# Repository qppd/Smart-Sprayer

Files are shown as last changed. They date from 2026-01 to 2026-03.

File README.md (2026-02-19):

# Smart-Sprayer

## Overview

The Smart-Sprayer is an advanced IoT-enabled agricultural device built on the ESP32 microcontroller platform. It provides intelligent, automated pesticide spraying with weather-aware operation and user-friendly button-based scheduling. The system features ultrasonic level monitoring, GSM SMS notifications, LCD status display, and comprehensive feedback systems for professional agricultural applications.

### Key Operational Flow
1. **System Startup**: ESP32 initializes all hardware components
2. **Button Scheduling**: User sets spray time using ESP32 buttons
3. **Automated Monitoring**: System continuously checks time and weather
4. **Weather Validation**: Prevents spraying during rain conditions
5. **Smart Activation**: Activates pumps when conditions are optimal
6. **Level Monitoring**: Real-time container level checking during operation
7. **Feedback System**: Professional audio-visual status indicators

## Features

### Core Functionality
- **Button-Based Scheduling**: Intuitive time setting using ESP32 buttons with LCD menu navigation
- **Weather-Aware Operation**: Automatic rain detection prevents unnecessary spraying
- **Container Level Monitoring**: Real-time ultrasonic measurement with low-level warnings
- **Automated Spraying**: Scheduled activation with intelligent condition checking
- **Professional Feedback**: Commercial-grade LED patterns and industrial buzzer tones
- **GSM Notifications**: SMS alerts for completion, postponement, and system events
- **Network Resilience**: Automatic reconnection with SMS retry mechanisms

### Advanced Features
- **Dual Relay Control**: Independent pump/valve operation for precision spraying
- **RTC Timekeeping**: Accurate scheduling with NTP synchronization and battery backup
- **Firebase Integration**: Cloud data logging and remote monitoring capabilities
- **WiFi Management**: Automatic configuration with captive portal fallback
- **Serial Diagnostics**: Comprehensive command interface for testing and configuration
- **Modular Architecture**: Clean separation of concerns with dedicated config headers

### System Architecture
- **ESP32 Microcontroller**: Dual-core processing with WiFi/Bluetooth
- **Ultrasonic Sensors**: HC-SR04 for precise container level measurement
- **GSM Module**: SIM800L for SMS communication and network monitoring
- **LCD Display**: 20x4 I2C interface for status and menu navigation
- **Relay System**: Dual-channel control for spray actuators
- **Button Interface**: 4-button navigation (WiFi reset + 3 menu controls)
- **RTC Module**: DS1302 for reliable timekeeping
- **Audio/Visual**: Buzzer and dual LED status indicators

### Notification System
The Smart-Sprayer includes a comprehensive notification system for operational awareness:

- **SMS Alerts**: Automatic notifications for spraying events (completion, postponement, errors)
- **Retry Logic**: Failed SMS messages are automatically retried up to 3 times
- **Network Monitoring**: GSM network disconnection triggers automatic reconnection attempts
- **Commercial Feedback**: Professional LED blinking patterns and industrial buzzer tones
- **Status Indicators**: Visual and audible feedback for all system operations

## System Flowchart

The project includes a detailed flowchart diagram showing the complete operational process:

```
diagram/SmartSprayer_Flowchart.md
```

This flowchart illustrates the step-by-step process from ESP32 button scheduling through automated spraying cycles, including decision points for weather checking, time validation, and level monitoring.

### Container Level Calculation
The ultrasonic sensor measures the distance from the sensor to the surface of the pesticide in the container. To calculate the fill percentage:

1. Define a variable for the total height of the container (e.g., `CONTAINER_HEIGHT` in cm)
2. Measure the distance from the sensor to the liquid surface using the SR04 sensor
3. Calculate the filled height: `filledHeight = CONTAINER_HEIGHT - measuredDistance`
4. Calculate the percentage: `percentage = (filledHeight / CONTAINER_HEIGHT) * 100`

This allows precise monitoring of pesticide levels to prevent running out during spraying operations.

## Hardware Requirements

### Microcontroller
- ESP32 development board (ESP32-WROOM-32 recommended) with built-in WiFi and Bluetooth

### Sensors and Modules
- HC-SR04 ultrasonic distance sensor (2 units)
- 20x4 I2C LCD display module
- GSM module (SIM800L or compatible)
- 2-channel relay module (5V or 12V based on application)
- Buzzer module (active/passive buzzer)
- LED indicators (2 units: OK and Error status)
- DS1302 RTC module (for accurate timekeeping)
- Push buttons (4 units: WiFi reset + 3 for menu navigation)

### Additional Components
- SIM card for GSM module
- Power supply (5V for ESP32, appropriate voltage for relays)
- Jumper wires and breadboard for prototyping
- Antenna for GSM module
- Internet connection for WiFi and Firebase functionality

### Pin Configuration
The system uses centralized pin definitions in `PINS_CONFIG.h` for easy modification:

| Component | Pin | Function | Notes |
|---|-----|---|---|
| Ultrasonic Sensor 1 | GPIO 12 | Trig | Trigger pin for ultrasonic pulses |
| Ultrasonic Sensor 1 | GPIO 13 | Echo | Echo pin for distance measurement |
| Ultrasonic Sensor 2 | GPIO 14 | Trig | Trigger pin for second sensor |
| Ultrasonic Sensor 2 | GPIO 16 | Echo | Echo pin for second sensor |
| Relay Module | GPIO 4 | Relay 1 Control | Controls first spray actuator |
| Relay Module | GPIO 5 | Relay 2 Control | Controls second spray actuator |
| GSM Module | GPIO 10 | RX | Receive data from GSM module |
| GSM Module | GPIO 11 | TX | Transmit data to GSM module |
| LCD Display | GPIO 21 | SDA | I2C data line (default ESP32 I2C) |
| LCD Display | GPIO 22 | SCL | I2C clock line (default ESP32 I2C) |
| Buzzer | GPIO 17 | Control | Audio alert output |
| System OK LED | GPIO 18 | Status | Indicates system OK state |
| System Error LED | GPIO 19 | Status | Indicates system error state |
| WiFi Reset Button | GPIO 23 | Input | Triggers WiFi manager reset (hold 3s) |
| Menu Up Button | GPIO 25 | Input | Menu navigation up |
| Menu Down Button | GPIO 26 | Input | Menu navigation down |
| Menu Select Button | GPIO 27 | Input | Menu select/save |
| DS1302 CE | GPIO 32 | Output | RTC chip enable |
| DS1302 I/O | GPIO 33 | I/O | RTC data line |
| DS1302 CLK | GPIO 14 | Output | RTC serial clock |

## Software Requirements

### Development Environment
- Arduino IDE 1.8.19 or later
- ESP32 board support package for Arduino IDE

### Required Libraries
- `LiquidCrystal_I2C` (for LCD display control)
- `SoftwareSerial` (for GSM module communication)
- `WiFiManager` (for WiFi configuration)
- `Firebase_ESP_Client` (for Firebase integration)
- `NTPClient` (for time synchronization)
- `HTTPClient` (for weather API requests)
- `ArduinoJson` (for parsing weather API responses)
- `Time` (for time management)
- `TimeAlarms` (for scheduled alarms)
- `RtcDS1302` (for DS1302 RTC module)

### Installation Steps
1. Install Arduino IDE from the official website
2. Add ESP32 board support:
   - Open Arduino IDE
   - Go to File > Preferences
   - Add `https://dl.espressif.com/dl/package_esp32_index.json` to Additional Board Manager URLs
   - Tools > Board > Boards Manager > Search for ESP32 > Install
3. Install required libraries:
   - Sketch > Include Library > Manage Libraries
   - Search and install the required libraries listed above

### Firebase Credentials Setup
1. Copy `source/esp32/SmartSprayer/FIREBASE_CREDENTIALS_template.h` to `source/esp32/SmartSprayer/FIREBASE_CREDENTIALS.h`
2. Fill in your Firebase project credentials:
   - WiFi SSID and password
   - Firebase API key and database URL
   - Service account credentials
   - User credentials (optional)
3. The `FIREBASE_CREDENTIALS.h` file is ignored by git to protect sensitive information

### GSM Recipients Setup
1. Copy `source/esp32/SmartSprayer/GSM_RECIPIENTS_template.h` to `source/esp32/SmartSprayer/GSM_RECIPIENTS.h`
2. Add your phone numbers to the recipients array
3. Set the `numRecipients` variable to the number of active recipients
4. The `GSM_RECIPIENTS.h` file is ignored by git to protect phone numbers

### Weather Credentials Setup
1. Copy `source/esp32/SmartSprayer/WEATHER_CREDENTIALS_template.h` to `source/esp32/SmartSprayer/WEATHER_CREDENTIALS.h`
2. Fill in your WeatherAPI credentials:
   - API key from https://www.weatherapi.com/
   - Location (e.g., "Manila" or city name)
3. The `WEATHER_CREDENTIALS.h` file is ignored by git to protect your API key

#### WeatherAPI Sample Call and Response
The system uses WeatherAPI for current weather monitoring. Here's a sample API call and response:

**API Call:**
```
GET https://api.weatherapi.com/v1/current.json?key=64812e322c3f4b42af7135146252012&q=Manila&aqi=no
```

**Sample Response:**
```json
{
    "location": {
        "name": "Manila",
        "region": "Manila",
        "country": "Philippines",
        "lat": 14.6042,
        "lon": 120.9822,
        "tz_id": "Asia/Manila",
        "localtime_epoch": 1766239111,
        "localtime": "2025-12-20 21:58"
    },
    "current": {
        "last_updated_epoch": 1766238300,
        "last_updated": "2025-12-20 21:45",
        "temp_c": 26.1,
        "temp_f": 79.0,
        "is_day": 0,
        "condition": {
            "text": "Partly cloudy",
            "icon": "//cdn.weatherapi.com/weather/64x64/night/116.png",
            "code": 1003
        },
        "wind_mph": 4.5,
        "wind_kph": 7.2,
        "wind_degree": 56,
        "wind_dir": "ENE",
        "pressure_mb": 1011.0,
        "pressure_in": 29.85,
        "precip_mm": 0.0,
        "precip_in": 0.0,
        "humidity": 84,
        "cloud": 75,
        "feelslike_c": 28.5,
        "feelslike_f": 83.4,
        "windchill_c": 25.2,
        "windchill_f": 77.3,
        "heatindex_c": 27.2,
        "heatindex_f": 81.0,
        "dewpoint_c": 21.1,
        "dewpoint_f": 70.0,
        "vis_km": 10.0,
        "vis_miles": 6.0,
        "uv": 0.0,
        "gust_mph": 6.6,
        "gust_kph": 10.6
    }
}
```

The system checks `current.precip_mm` and `current.condition.text` to determine if it's raining.

### Security Note
- Never commit `FIREBASE_CREDENTIALS.h`, `GSM_RECIPIENTS.h`, or `WEATHER_CREDENTIALS.h` to version control
- Use the provided templates to create your configuration files
- Regularly rotate API keys, passwords, and phone numbers
- Use Firebase security rules to protect your database

## Installation and Setup

### Repository Setup
```bash
git clone https://github.com/qppd/Smart-Sprayer.git
cd Smart-Sprayer
```

### Hardware Assembly

#### Wiring Diagrams
Refer to the wiring diagrams in the `wiring/` directory for complete circuit connections:
- [Smart-Sprayer.fzz](wiring/Smart-Sprayer.fzz) - Fritzing diagram file
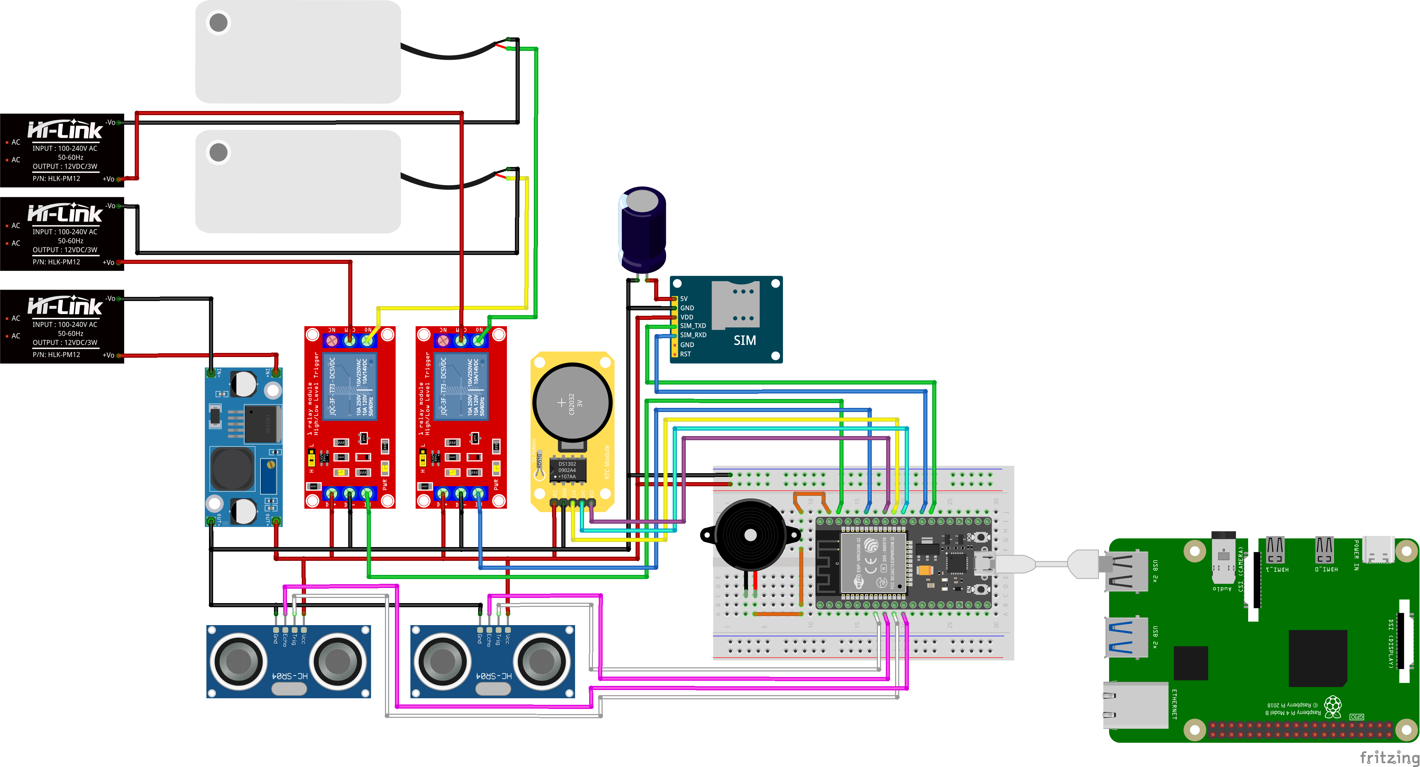
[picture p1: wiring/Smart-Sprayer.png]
Smart-Sprayer Wiring Diagram
- 

#### 3D Design Models
The `model/` directory contains 3D design files and reference images for the Smart-Sprayer hardware enclosure:

**Board Case (Main Enclosure)**
- [Smart_Sprayer_Board_Case.stl](model/Smart_Sprayer_Board_Case.stl) - 3D model of the main board case for 3D printing
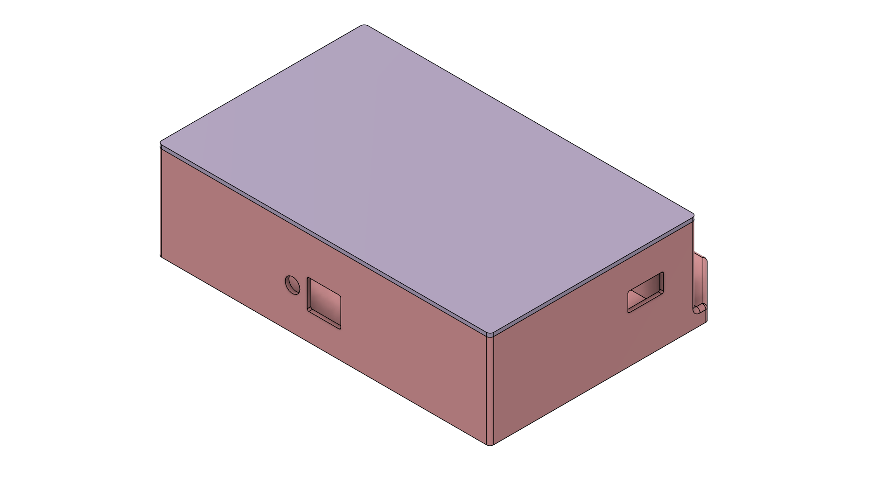
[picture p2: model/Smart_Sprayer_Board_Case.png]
-  - Reference image of the board case design

**Case Cover**
- [Smart_Sprayer_Board_Case_Cover.stl](model/Smart_Sprayer_Board_Case_Cover.stl) - 3D model of the case cover/lid
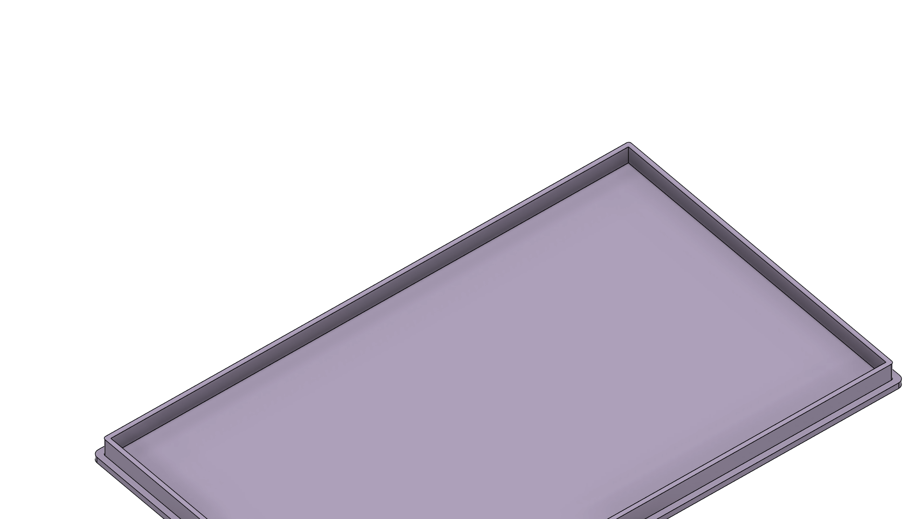
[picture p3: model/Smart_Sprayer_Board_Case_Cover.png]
-  - Reference image of the case cover

**Full Assembly Views**
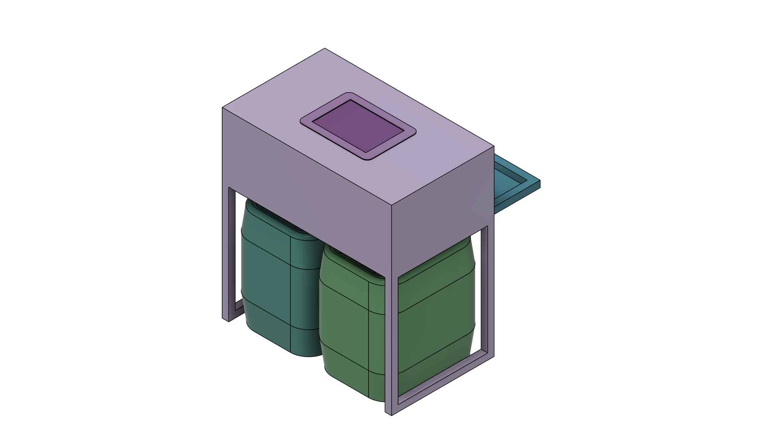
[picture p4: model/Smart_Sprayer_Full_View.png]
-  - Complete assembled system showing all components integrated in the enclosure with proper cable routing and sensor placement
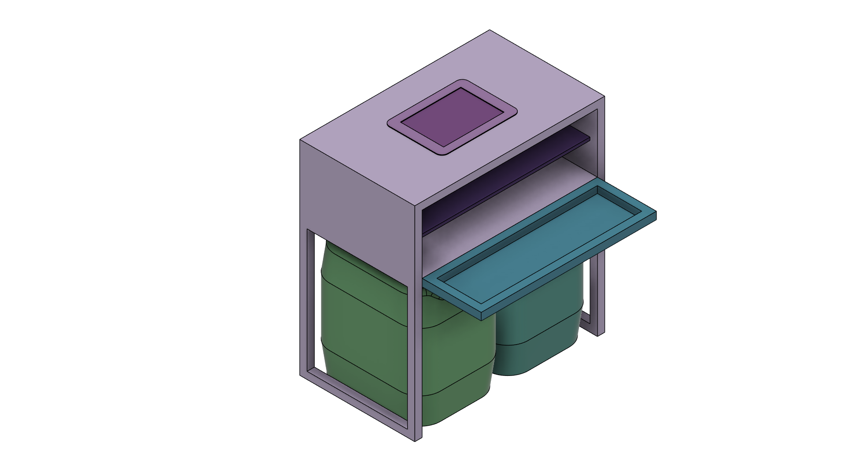
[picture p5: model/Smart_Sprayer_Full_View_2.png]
-  - Alternative angle of the assembled system demonstrating full device configuration and component visibility

#### Assembly Instructions
1. Connect the ultrasonic sensor to GPIO 12 (Trig) and GPIO 13 (Echo)
2. Wire the relay module to GPIO 4 and GPIO 5
3. Connect GSM module to GPIO 10 (RX) and GPIO 11 (TX)
4. Attach the I2C LCD to the default I2C pins (GPIO 21 SDA, GPIO 22 SCL)
5. Connect the WiFi reset button to GPIO 23 (with pull-up resistor)
6. Connect menu navigation buttons: Up to GPIO 25, Down to GPIO 26, Select to GPIO 27
7. Connect DS1302 RTC: CE to GPIO 32, I/O to GPIO 33, CLK to GPIO 14
8. Insert SIM card into GSM module and attach antenna
9. Power the system with appropriate voltage sources

### Software Upload
1. Open `source/esp32/SmartSprayer/SmartSprayer.ino` in Arduino IDE
2. Select ESP32 Dev Module from Tools > Board
3. Choose the correct COM port
4. Click Upload to flash the firmware

## Usage

### Basic Operation
1. **Power On**: Connect power to the ESP32 board
2. **System Initialization**: LCD displays startup sequence and component status
3. **Ready State**: System shows "System Ready" when all components are initialized
4. **Button Scheduling**: Use the 4 buttons to set spray schedules and monitor status

### Button Interface
The system uses 4 buttons for complete operation:

| Button | GPIO Pin | Function |
|---|---|---|
| **WiFi Reset** | GPIO 23 | Hold 3s to reset WiFi settings |
| **Menu Up** | GPIO 25 | Navigate menus up / increment values |
| **Menu Down** | GPIO 26 | Navigate menus down / decrement values |
| **Menu Select** | GPIO 27 | Select items / confirm settings |

### Scheduling Process
1. **Enter Scheduling**: Press any menu button when system is ready
2. **Navigate Menu**: Use Up/Down buttons to select "Schedule Spray"
3. **Set Time**: Use Up/Down buttons to adjust hour and minute
4. **Confirm**: Press Select button to save the schedule
5. **Monitor**: LCD displays scheduled time and system status

### Automated Operation
Once scheduled, the system operates automatically:
- **Time Check**: Compares current time with scheduled spray time
- **Weather Validation**: Checks for rain conditions before spraying
- **Pump Activation**: Activates relays when conditions are optimal
- **Level Monitoring**: Continuously monitors container levels during spraying
- **Completion Feedback**: Provides audio-visual confirmation when done
- **Cycle Repeat**: Returns to monitoring for next scheduled spray

### WiFi Configuration
- **Normal Operation**: System connects to saved WiFi network automatically
- **Reset Mode**: Hold WiFi reset button (GPIO 23) for 3 seconds during boot
- **AP Mode**: System creates "SmartSprayer-Setup" access point for configuration
- **Web Portal**: Connect to AP and open 192.168.4.1 in browser to configure WiFi

### Serial Diagnostics Interface
The system provides a serial diagnostics interface for advanced troubleshooting and configuration. Connect to the ESP32 using Arduino Serial Monitor at 9600 baud rate. This interface is primarily for maintenance and diagnostics - normal operation is fully automated through the button interface.

#### Available Diagnostic Commands

##### System Diagnostics
- `check-network`: Queries GSM network registration status
- `get-distance1`: Retrieves current distance measurement from ultrasonic sensor 1
- `get-distance2`: Retrieves current distance measurement from ultrasonic sensor 2
- `get-level`: Calculates and displays container fill level and percentage
- `check-weather`: Fetches current weather and checks for rain
- `get-time`: Retrieves and displays current formatted date/time
- `wifi-reset`: Resets WiFi settings and restarts in AP mode

##### Component Testing (Maintenance Only)
- `operate-relay1_on/off`: Manual relay control for testing
- `buzzer-beep`: Test buzzer functionality
- `led-ok/error/warning/clear`: Test LED indicators
- `test-display`: Display test information on LCD
- `send-sms`: Send test SMS message

### Command Usage Examples
```
get-level
Distance: 45 cm, Filled: 55 cm, Percentage: 55 %

check-weather
Weather check: No rain currently - safe to spray

get-time
Current time: 2025-12-20 14:30:25
```

## API Reference

### LCD Functions (LCD_CONFIG.h)
- `void initLCD()`: Initializes the LCD display
- `void clearLCD()`: Clears the LCD screen
- `void setLCDText(String text, int x, int y)`: Displays text at specified coordinates
- `void setLCDText(double value, int x, int y)`: Displays numeric value at coordinates
- `void setLCDText(float value, int x, int y)`: Displays float value at coordinates
- `void setLCDText(int value, int x, int y)`: Displays integer value at coordinates
- `void setLCDText(char text, int x, int y)`: Displays character at coordinates

### PIN Configuration (PINS_CONFIG.h)
- Centralized pin definitions for all hardware components
- Easy to modify pin assignments without changing multiple files

### Buzzer Functions (BUZZER_CONFIG.h)
- `void initBuzzer()`: Initializes buzzer pin
- `void buzzerOn()`: Turns buzzer on continuously
- `void buzzerOff()`: Turns buzzer off
- `void buzzerBeep(int duration_ms)`: Produces a beep for specified duration

### LED Functions (LED_CONFIG.h)
- `void initLEDs()`: Initializes LED pins
- `void setSystemOK()`: Turns on OK LED, off error LED
- `void setSystemError()`: Turns on error LED, off OK LED
- `void setSystemWarning()`: Turns on both LEDs
- `void clearSystemLEDs()`: Turns off both LEDs

### Button Functions (BUTTON_CONFIG.h)
- `void initBUTTONS()`: Initializes all 4 buttons with pull-up resistors
- `void setInputFlags()`: Reads and debounces button states
- `void resolveInputFlags()`: Processes button presses and calls appropriate actions
- `void inputAction(int buttonIndex)`: Handles button press actions (WiFi reset, menu navigation)
- `void enterSchedulingMode()`: Activates spray scheduling interface
- `void exitSchedulingMode()`: Returns to main menu
- `void scheduleSprayAlarm(int hour, int minute)`: Sets daily spray alarm
- `void cancelSprayAlarm()`: Removes existing spray alarm

### RTC Functions (RTC_CONFIG.h)
- `void initRTC()`: Initializes DS1302 RTC module and syncs with system time
- `void syncRTCWithNTP()`: Synchronizes RTC with NTP time (called once during setup)
- `bool isRTCValid()`: Checks if RTC time is valid
- `String getRTCDateTimeString()`: Returns formatted RTC date/time string
- `void updateSystemTimeFromRTC()`: Updates system time from RTC

### GSM Functions (GSM_CONFIG.h)
- `void initGSM()`: Initializes GSM module communication
- `void sendSMS(String number, String message)`: Sends SMS to specified number
- `void sendSMSToAll(String message)`: Sends SMS to all configured numbers
- `void checkNetwork()`: Checks GSM network registration status

### Relay Functions (RELAY_CONFIG.h)
- `void initRELAY()`: Sets up relay control pins
- `void operateRELAY(uint16_t RELAY, boolean OPENED)`: Controls relay state

### Ultrasonic Functions (SR04_CONFIG.h)
- `void initSR04()`: Initializes ultrasonic sensor pins
- `long readDistance()`: Returns distance measurement in centimeters from sensor 1 (used for container level monitoring)
- `long readDistance2()`: Returns distance measurement in centimeters from sensor 2
- `float calculateFillLevel(long distance)`: Calculates filled height in container (container height - distance)
- `float calculateFillPercentage(long distance)`: Calculates fill percentage (0-100%)

### WiFi Functions (WIFI_CONFIG.h)
- `void initWIFI()`: Initializes WiFi connection with auto-configuration portal

### Firebase Functions (FIREBASE_CONFIG.h)
- `void initFIREBASE()`: Initializes Firebase connection and streams
- `void updateDeviceCurrent(...)`: Updates current device state in Firebase
- `void logDeviceData(...)`: Logs device data with timestamp
- `void sendSmartSprayerData(...)`: Sends Smart Sprayer data to Firebase
- `void sendMessage(...)`: Sends FCM notification
- `void sendMessageToAll(...)`: Sends FCM to all registered devices
- `void handleStreams()`: Processes Firebase real-time streams
- `bool isReady()`: Checks Firebase connection status

### NTP Functions (NTP_CONFIG.h)
- `void initNTP()`: Initializes NTP time synchronization
- `void getNTPDate()`: Retrieves and formats current date/time
- `unsigned long getNTPTimestamp()`: Gets Unix timestamp from NTP
- `unsigned long getNTPTimestampWithFallback()`: NTP timestamp with automatic fallback
- `bool isNTPSynced()`: Checks if NTP time is synchronized
- `String getFormattedDateTime()`: Returns formatted date/time string
- `String getFormattedDateTimeWithFallback()`: Formatted time with fallback indication
- `String getCurrentLogPrefix()`: Provides timestamp prefix for logging

### Weather Functions (WEATHER_CONFIG.h)
- `bool checkWeatherForRain()`: Fetches current weather and returns true if it's raining

## Project Structure

```
Smart-Sprayer/
├── .gitignore
├── LICENSE
├── README.md
├── FIREBASE_CREDENTIALS_template.h
├── diagram/
│   └── [circuit diagrams and schematics]
├── model/
│   ├── SmartSprayer_Board_Case.stl
│   ├── Smart_Sprayer_Board_Case.png
│   ├── Smart_Sprayer_Board_Case_Cover.stl
│   ├── Smart_Sprayer_Board_Case_Cover.png
│   ├── Smart_Sprayer_Full_View.png
│   └── Smart_Sprayer_Full_View_2.png
├── source/
│   └── esp32/
│       └── SmartSprayer/
│           ├── SmartSprayer.ino
│           ├── PINS_CONFIG.h
│           ├── PINS_CONFIG.h
│           ├── LCD_CONFIG.h
│           ├── GSM_CONFIG.h
│           ├── GSM_RECIPIENTS.h (ignored)
│           ├── GSM_RECIPIENTS_template.h
│           ├── RELAY_CONFIG.h
│           ├── SR04_CONFIG.h
│           ├── WIFI_CONFIG.h
│           ├── FIREBASE_CONFIG.h
│           ├── NTP_CONFIG.h
│           ├── WEATHER_CONFIG.h
│           ├── BUZZER_CONFIG.h
│           ├── LED_CONFIG.h
│           ├── BUTTON_CONFIG.h
│           ├── RTC_CONFIG.h
│           ├── WEATHER_CREDENTIALS.h (ignored)
│           ├── WEATHER_CREDENTIALS_template.h
│           ├── FIREBASE_CREDENTIALS.h (ignored)
│           └── FIREBASE_CREDENTIALS_template.h
└── wiring/
    └── [wiring diagrams and instructions]
```

## Configuration

### GSM Module Configuration
Edit `GSM_CONFIG.h` to modify:
- Phone numbers for SMS recipients
- GSM module pins (if different from defaults)
- Communication baud rate

### LCD Configuration
Modify LCD parameters in `LCD_CONFIG.h`:
- I2C address (default: 0x27)
- Display dimensions (default: 20x4)

### Relay Configuration
Adjust relay settings in `RELAY_CONFIG.h`:
- GPIO pins for relays
- Relay logic (active high/low)

### Ultrasonic Sensor Configuration
Configure sensor parameters in `SR04_CONFIG.h`:
- Trigger and echo pins
- Measurement timing parameters

### Button Configuration
Configure WiFi reset button settings in `BUTTON_CONFIG.h`:
- Button pin assignment
- Debounce delay
- Hold time for WiFi reset trigger

## Troubleshooting

### Common Issues

#### ESP32 Not Detected
- Ensure correct COM port selection in Arduino IDE
- Check USB cable and drivers
- Try different USB port

#### LCD Not Displaying
- Verify I2C connections and address
- Check power supply to LCD
- Confirm I2C pins (SDA: GPIO 21, SCL: GPIO 22)

#### GSM Not Responding
- Check SIM card insertion and PIN status
- Verify antenna connection
- Ensure sufficient signal strength
- Check GSM module power supply

#### Ultrasonic Sensor Inaccurate Readings
- Ensure clear line of sight for sensor
- Check voltage levels (5V required)
- Verify pin connections
- Test with known distances

#### Relay Not Activating
- Confirm relay module power supply
- Check GPIO pin assignments
- Verify relay logic (normally open/closed)

#### Weather API Issues
- Ensure valid OpenWeatherMap API key in `WEATHER_CREDENTIALS.h`
- Check WiFi connection for API requests
- Verify location format (e.g., "Manila,PH")
- Monitor serial output for API error codes

### Debug Mode
Enable serial debugging by monitoring the Serial output at 9600 baud. The system provides detailed status messages during initialization and operation.

## Contributing

We welcome contributions to the Smart-Sprayer project. Please follow these guidelines:

1. Fork the repository
2. Create a feature branch (`git checkout -b feature/AmazingFeature`)
3. Commit your changes (`git commit -m 'Add some AmazingFeature'`)
4. Push to the branch (`git push origin feature/AmazingFeature`)
5. Open a Pull Request

### Development Guidelines
- Maintain modular code structure
- Add comments for complex logic
- Test all changes thoroughly
- Update documentation for new features
- Follow Arduino coding standards

## License

This project is licensed under the terms specified in the LICENSE file. See LICENSE for details.

## Acknowledgments

- ESP32 community for microcontroller support
- Arduino framework developers
- Open-source library contributors

## Contact

For questions, issues, or contributions, please use the GitHub repository's issue tracker or pull request system.

## Contact

- Email: [quezon.province.pd@gmail.com](mailto:quezon.province.pd@gmail.com)
- GitHub: [github.com/qppd](https://github.com/qppd)
- Portfolio: [sajed-mendoza.onrender.com](https://sajed-mendoza.onrender.com)
- Facebook: [facebook.com/qppd.dev](https://facebook.com/qppd.dev)
- Facebook Page: [facebook.com/QUEZONPROVINCEDEVS](https://facebook.com/QUEZONPROVINCEDEVS)

## Author

Created by qppd

## GitHub Repository

This project is hosted on GitHub at: https://github.com/qppd/Smart-Sprayer

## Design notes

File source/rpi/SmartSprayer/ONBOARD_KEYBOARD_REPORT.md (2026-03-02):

# Onboard Virtual Keyboard Integration Report
**Project:** SmartSprayerV2  
**Generated:** 2026-03-02  
**Purpose:** Identify all keyboard-interactive widgets and provide actionable guidance for implementing auto-show/hide Onboard virtual keyboard logic in fullscreen mode.

---

## Overview

| Screen | Input Widgets Found | Onboard Risk Level |
|---|---|---|
| Login (`run_gui.py – LoginScreen`) | 2 | 🔴 High – fullscreen CTk window |
| Mobile Number Setup (`run_gui.py – MobileNumberScreen`) | 1 | 🔴 High – fullscreen CTk window |
| Scheduling (`ui/scheduling.py`) | 5 | 🟠 Medium – embedded panel |
| Settings (`ui/settings.py`) | 3 active + 2 read-only | 🟠 Medium – scrollable panel |
| Account / Change Password (`ui/account.py`) | 3 | 🟠 Medium – embedded panel |
| Legacy Login (`ui/SmartSprayerUI.py`) | 3 | 🟡 Low – older screen |
| Logs Viewer (`ui/spraying_events_logs_viewer.py`) | 1 (read-only) | ⚪ None – display only |

---

## Detailed Widget Inventory

### 1. Login Screen — `run_gui.py` › `LoginScreen`

| # | Variable | Widget Type | Context | Input Type | Onboard Behavior |
|---|---|---|---|---|---|
| 1 | `self.user` | `CTkEntry` | Username field | Text (alphanumeric) | **Auto-show on `<FocusIn>`, hide on `<FocusOut>`** |
| 2 | `self.passw` | `CTkEntry` | Password field (`show="•"`) | Password (masked) | **Auto-show on `<FocusIn>`, hide on `<FocusOut>`** |

**⚠ Fullscreen Risk:** `LoginScreen` is a `ctk.CTk()` window with `-fullscreen True`. Onboard **does not auto-raise** over fullscreen windows by default. Must call `subprocess.Popen(["onboard"])` explicitly on focus and `subprocess.run(["pkill", "onboard"])` on destroy/submit.

---

### 2. Mobile Number Setup Screen — `run_gui.py` › `MobileNumberScreen`

| # | Variable | Widget Type | Context | Input Type | Onboard Behavior |
|---|---|---|---|---|---|
| 3 | `self.phone_entry` | `CTkEntry` | 10-digit phone number | Numeric only | **Auto-show on `<FocusIn>`, numeric layout preferred** |

**⚠ Fullscreen Risk:** Same as LoginScreen — standalone `ctk.CTk()` fullscreen window.

---

### 3. Scheduling Panel — `ui/scheduling.py` › `SchedulingPanel`

| # | Variable | Widget Type | Context | Input Type | Onboard Behavior |
|---|---|---|---|---|---|
| 4 | `self.vol_entry` | `CTkEntry` | Volume (mL) input in new schedule form | Numeric | Auto-show on `<FocusIn>`, hide on `<FocusOut>` |
| 5 | `self.interval_entry` | `CTkEntry` | Recurring interval in days (e.g. `7`) | Numeric | Auto-show on `<FocusIn>`, hide on `<FocusOut>` |
| 6 | `self.count_entry` | `CTkEntry` | Recurring count (e.g. `4`) | Numeric | Auto-show on `<FocusIn>`, hide on `<FocusOut>` |
| 7 | `new_vol_entry` *(local var)* | `CTkEntry` | Volume field inside **Edit Schedule** modal/row | Numeric | Auto-show on `<FocusIn>` – note: local var, bind at creation time |
| 8 | ComboBox (time pickers) | `CTkComboBox` | Hour / Minute selectors (`state="readonly"`) | Dropdown only | ⚪ No keyboard needed – read-only dropdown |

**Note on `new_vol_entry`:** This is a local variable created dynamically inside a function (around line 909). The `<FocusIn>` binding must be applied immediately after widget creation since there is no `self.*` reference.

---

### 4. Settings Panel — `ui/settings.py` › `SettingsFrame`

| # | Variable | Widget Type | Context | Input Type | Onboard Behavior |
|---|---|---|---|---|---|
| 9 | `self.phone_entry` | `CTkEntry` | SMS recipient phone number | Numeric (validated) | Auto-show on `<FocusIn>`, hide on `<FocusOut>` |
| 10 | `self.name_entry` | `CTkEntry` | SMS recipient name | Text (optional) | Auto-show on `<FocusIn>`, hide on `<FocusOut>` |
| 11 | `self._wifi_pw_entry` | `CTkEntry` | WiFi password (`show="●"`) | Password (masked) | Auto-show on `<FocusIn>`, hide on `<FocusOut>` |
| — | `prefix` *(local)* | `CTkEntry` | `+63` prefix – **disabled** | Read-only | ⚪ Skip – `state="disabled"` |
| — | `self.muni` | `CTkComboBox` | Municipality selector | Dropdown only | ⚪ No keyboard needed – read-only dropdown |
| — | `self.brgy` | `CTkComboBox` | Barangay selector | Dropdown only | ⚪ No keyboard needed – read-only dropdown |
| — | `self._wifi_ssid_menu` | `CTkComboBox` | WiFi SSID selector | Dropdown only | ⚪ No keyboard needed – read-only dropdown |

---

### 5. Account / Change Password — `ui/account.py` › `SprayerAccountPanel`

| # | Variable | Widget Type | Context | Input Type | Onboard Behavior |
|---|---|---|---|---|---|
| 12 | `self.current_pass` | `CTkEntry` | Current password (`show="•"`) | Password (masked) | Auto-show on `<FocusIn>`, hide on `<FocusOut>` |
| 13 | `self.new_pass` | `CTkEntry` | New password (`show="•"`) | Password (masked) | Auto-show on `<FocusIn>`, hide on `<FocusOut>` |
| 14 | `self.confirm_pass` | `CTkEntry` | Confirm password (`show="•"`) | Password (masked) | Auto-show on `<FocusIn>`, hide on `<FocusOut>` |

*All three are created via `_password_field()` helper at lines ~230–240 of `account.py`.*

---

### 6. Legacy Login Screen — `ui/SmartSprayerUI.py`

| # | Variable | Widget Type | Context | Input Type | Onboard Behavior |
|---|---|---|---|---|---|
| 15 | `self.user_entry` | `CTkEntry` | Username | Text | Auto-show on `<FocusIn>` |
| 16 | `self.pass_entry` | `CTkEntry` | Password (`show="*"`) | Password | Auto-show on `<FocusIn>` |
| 17 | `self.mobile_entry` | `CTkEntry` | Mobile number | Numeric | Auto-show on `<FocusIn>` |

**Note:** This screen appears to be a legacy/alternate entry point. If still in use, apply the same fullscreen Onboard strategy as `run_gui.py`.

---

### 7. Logs Viewer — `ui/spraying_events_logs_viewer.py`

| # | Variable | Widget Type | Context | Input Type | Onboard Behavior |
|---|---|---|---|---|---|
| — | `self.log_textbox` | `CTkTextbox` | Log display area | **Read-only display** | ⚪ Skip – set `state="disabled"` to prevent cursor focus |

---

## Fullscreen Onboard Problem — Root Cause

By default, Onboard cannot float above a fullscreen Tkinter/CTk window because:
1. The fullscreen window grabs the entire display layer.
2. Onboard's `--not-docked` mode is blocked by the window manager.

### Recommended Fix

Use **`onboard --layout=Phone`** (or compact layout) launched via subprocess, combined with the main window being set to a **maximized window** (not true fullscreen):

```python
# Instead of:
self.attributes("-fullscreen", True)

# Use:
self.state("zoomed")          # Windows
# or
self.attributes("-zoomed", True)  # Linux/RPi
```

If true fullscreen is required, use this approach:

```python
import subprocess
import os

_onboard_proc = None

def show_keyboard():
    global _onboard_proc
    if _onboard_proc is None or _onboard_proc.poll() is not None:
        _onboard_proc = subprocess.Popen(
            ["onboard", "--size=800x300", "--layout=Phone", "--theme=Nightshade"],
            stdout=subprocess.DEVNULL, stderr=subprocess.DEVNULL
        )

def hide_keyboard():
    global _onboard_proc
    if _onboard_proc and _onboard_proc.poll() is None:
        _onboard_proc.terminate()
        _onboard_proc = None
```

---

## Reusable Binding Helper

Add this function to a shared utility module (e.g., `ui/__init__.py` or a new `ui/keyboard_utils.py`):

```python
# ui/keyboard_utils.py

import subprocess

_onboard_proc = None

def show_keyboard():
    """Launch Onboard virtual keyboard if not already running."""
    global _onboard_proc
    if _onboard_proc is None or _onboard_proc.poll() is not None:
        _onboard_proc = subprocess.Popen(
            ["onboard", "--size=800x280", "--layout=Phone"],
            stdout=subprocess.DEVNULL,
            stderr=subprocess.DEVNULL
        )

def hide_keyboard():
    """Terminate Onboard virtual keyboard."""
    global _onboard_proc
    if _onboard_proc and _onboard_proc.poll() is None:
        _onboard_proc.terminate()
        _onboard_proc = None

def bind_keyboard(widget):
    """
    Bind Onboard show/hide to any CTkEntry or CTkTextbox widget.
    Call this once after widget creation.

    Usage:
        bind_keyboard(self.phone_entry)
        bind_keyboard(self.passw)
    """
    # CTkEntry wraps an internal tk.Entry — bind on the inner widget
    inner = getattr(widget, "_entry", None) or widget
    inner.bind("<FocusIn>",  lambda e: show_keyboard(), add="+")
    inner.bind("<FocusOut>", lambda e: hide_keyboard(), add="+")
```

---

## Implementation Checklist

### `run_gui.py`
- [ ] Import `bind_keyboard` from `ui.keyboard_utils`
- [ ] `bind_keyboard(self.user)` in `LoginScreen.__init__`
- [ ] `bind_keyboard(self.passw)` in `LoginScreen.__init__`
- [ ] `bind_keyboard(self.phone_entry)` in `MobileNumberScreen.__init__`
- [ ] Call `hide_keyboard()` in `login()` and `submit()` methods before destroy
- [ ] Replace `-fullscreen True` with `state("zoomed")` OR ensure Onboard uses `--not-docked` mode

### `ui/scheduling.py`
- [ ] Import `bind_keyboard`
- [ ] `bind_keyboard(self.vol_entry)` after creation
- [ ] `bind_keyboard(self.interval_entry)` after creation
- [ ] `bind_keyboard(self.count_entry)` after creation
- [ ] `bind_keyboard(new_vol_entry)` immediately after creation in the edit helper

### `ui/settings.py`
- [ ] Import `bind_keyboard`
- [ ] `bind_keyboard(self.phone_entry)` in `create_sms_card()`
- [ ] `bind_keyboard(self.name_entry)` in `create_sms_card()`
- [ ] `bind_keyboard(self._wifi_pw_entry)` in `create_wifi_card()`

### `ui/account.py`
- [ ] Import `bind_keyboard`
- [ ] `bind_keyboard(self.current_pass)` after `_password_field()` call
- [ ] `bind_keyboard(self.new_pass)` after `_password_field()` call
- [ ] `bind_keyboard(self.confirm_pass)` after `_password_field()` call

### `ui/SmartSprayerUI.py` (legacy)
- [ ] Import `bind_keyboard`
- [ ] `bind_keyboard(self.user_entry)`
- [ ] `bind_keyboard(self.pass_entry)`
- [ ] `bind_keyboard(self.mobile_entry)`

### Global
- [ ] Create `ui/keyboard_utils.py` with the helper above
- [ ] Consider calling `hide_keyboard()` from `SmartSprayerUI._on_closing()`
- [ ] Test Onboard visibility with `--not-docked` and/or switch from `-fullscreen` to `state("zoomed")`

---

## Summary by Priority

| Priority | File | Action |
|---|---|---|
| 🔴 Critical | `run_gui.py` | Fullscreen blocks Onboard — switch to `zoomed` + bind all 3 entries |
| 🔴 Critical | `run_gui.py` | Call `hide_keyboard()` on login/submit/screen switch |
| 🟠 High | `ui/settings.py` | Bind `phone_entry`, `name_entry`, `_wifi_pw_entry` |
| 🟠 High | `ui/scheduling.py` | Bind `vol_entry`, `interval_entry`, `count_entry`, `new_vol_entry` |
| 🟠 High | `ui/account.py` | Bind `current_pass`, `new_pass`, `confirm_pass` |
| 🟡 Medium | `ui/SmartSprayerUI.py` | Bind if this screen is still live |
| ⚪ None | `ui/spraying_events_logs_viewer.py` | Disable `log_textbox` to prevent accidental keyboard focus |

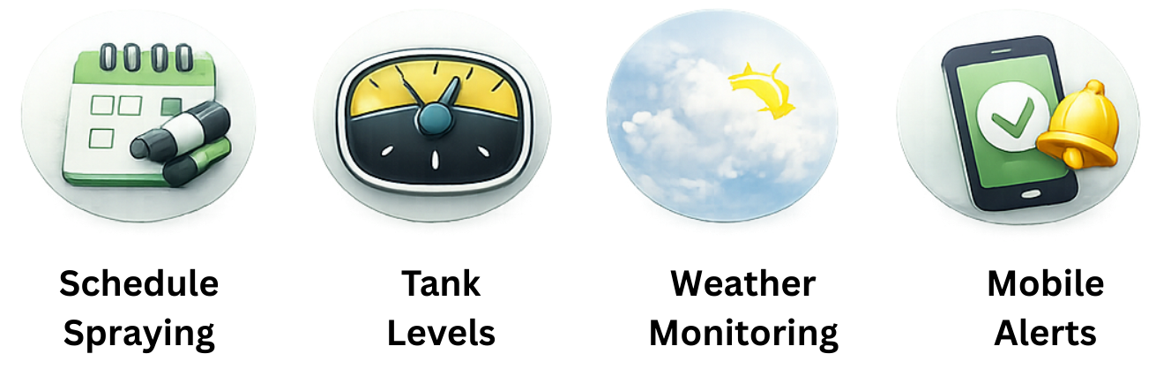
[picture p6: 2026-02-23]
source/rpi/SmartSprayer/start.png

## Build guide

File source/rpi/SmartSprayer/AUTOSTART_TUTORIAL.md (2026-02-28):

# Smart Sprayer V2 — Autostart on Boot (Raspberry Pi)

> **Target hardware:** Raspberry Pi 4 (or 3B+) · LCD Touchscreen (DSI or HDMI) · WiFi  
> **OS:** Raspberry Pi OS with Desktop (Bullseye or Bookworm, 32-bit or 64-bit)

---

## Overview

This guide walks you through setting up `run_gui.py` to launch automatically on every boot, **after WiFi is connected**, using a **systemd service**. The app runs in fullscreen on the LCD touchscreen.

---

## Prerequisites Checklist

Before starting, confirm each item:

- [ ] Raspberry Pi OS **with Desktop** is installed and working
- [ ] The LCD touchscreen is connected and displays the desktop at boot
- [ ] **Autologin is enabled** (desktop boots directly without a password prompt)
- [ ] WiFi credentials are saved (`sudo raspi-config` → System → Wireless LAN)
- [ ] Python 3.9+ is installed (`python3 --version`)
- [ ] All Python packages in `requirements.txt` are installed (see Step 2)
- [ ] Firebase credentials are set up in `firebase_credentials.py`

---

## Step 1 — Enable Desktop Autologin

The GUI app requires the graphical desktop (X11/Wayland) to already be running, which only happens after autologin.

```bash
sudo raspi-config
```

Navigate to:

```
1 System Options  →  S5 Boot / Auto Login  →  B4 Desktop Autologin
```

Select **B4 Desktop Autologin** — this boots straight to the desktop as the `pi` user without a password prompt. Choose **Finish** and **reboot**.

> If your username is not `pi` (e.g. `sprayer`), replace every occurrence of `pi` in this guide with your actual username. Verify with `whoami`.

---

## Step 2 — Install Python Dependencies

SSH into the Pi (or open a terminal on the Pi) and run:

```bash
cd /home/pi/SmartSprayerV2
pip3 install -r requirements.txt
```

Verify key packages are present:

```bash
python3 -c "import customtkinter, PIL, firebase_admin; print('OK')"
```

If you see `OK`, all required libraries are installed.

---

## Step 3 — Confirm the App Runs Manually

Always test manually before setting up autostart. From a terminal **on the Pi desktop** (not SSH):

```bash
cd /home/pi/SmartSprayerV2
python3 run_gui.py
```

Confirm:
- The fullscreen splash screen appears
- The Welcome screen appears  
- Login works (`sprayer` / `1234`)
- The dashboard loads and displays sensor data

Press **Escape** or use the app's exit mechanism to close. If the app does not run correctly now, fix it before proceeding — the service will have the same problem.

---

## Step 4 — Find Your Python Interpreter Path

The service file needs the absolute path to Python:

```bash
which python3
```

Typical output: `/usr/bin/python3`

If you use a virtual environment (e.g. `venv`), activate it first and run `which python3` to get the venv path, e.g. `/home/pi/venv/bin/python3`.

---

## Step 5 — Determine Your Display Server (X11 or Wayland)

Run this command on the Pi desktop terminal:

```bash
echo $XDG_SESSION_TYPE
```

| Output | Display server  | Notes |
|---|---|---|
| `x11` | X11 (Xorg) | Bullseye default, most Pi setups |
| `wayland` | Wayland | Bookworm default (Pi 4/5 only) |

Keep this answer — you'll use it in Step 6.

---

## Step 6 — Create the systemd Service File

Create the service file using nano (or any editor):

```bash
sudo nano /etc/systemd/system/smart-sprayer.service
```

### Option A — X11 (most common)

Paste the following (edit paths if your username or app location differs):

```ini
[Unit]
Description=Smart Sprayer V2 GUI
# Wait for the desktop environment AND network before starting
After=graphical.target network-online.target
Wants=network-online.target graphical.target

[Service]
Type=simple
User=pi
Group=pi
# Point to the app directory
WorkingDirectory=/home/pi/SmartSprayerV2

# X11 display and auth — required for any GUI app
Environment=DISPLAY=:0
Environment=XAUTHORITY=/home/pi/.Xauthority

# Prevent the app from starting before the X server is accepting connections
ExecStartPre=/bin/sleep 5

# The main command — adjust python3 path if using a venv
ExecStart=/usr/bin/python3 /home/pi/SmartSprayerV2/run_gui.py

# Restart the app if it crashes
Restart=on-failure
RestartSec=10

# Log stdout/stderr to the systemd journal (view with: journalctl -u smart-sprayer)
StandardOutput=journal
StandardError=journal

[Install]
WantedBy=graphical.target
```

### Option B — Wayland (Raspberry Pi OS Bookworm)

```ini
[Unit]
Description=Smart Sprayer V2 GUI
After=graphical.target network-online.target
Wants=network-online.target graphical.target

[Service]
Type=simple
User=pi
Group=pi
WorkingDirectory=/home/pi/SmartSprayerV2

# Wayland display variables
Environment=WAYLAND_DISPLAY=wayland-0
Environment=XDG_RUNTIME_DIR=/run/user/1000
Environment=DISPLAY=:0

ExecStartPre=/bin/sleep 5
ExecStart=/usr/bin/python3 /home/pi/SmartSprayerV2/run_gui.py

Restart=on-failure
RestartSec=10
StandardOutput=journal
StandardError=journal

[Install]
WantedBy=graphical.target
```

Save and exit: **Ctrl+O → Enter → Ctrl+X**

> **App location:** The tutorial assumes the app is at `/home/pi/SmartSprayerV2/`. If you cloned the repository elsewhere (e.g., `/home/pi/Desktop/Smart-Sprayer/source/rpi/SmartSprayerV2/`), update `WorkingDirectory` and `ExecStart` accordingly.

---

## Step 7 — Copy App Files to the Pi

If you are developing on Windows and transferring files to the Pi, use `scp` or `rsync`. From your Windows machine:

```powershell
# Replace PI_IP with your Pi's IP address
scp -r "C:\Users\sajed\Desktop\PROJECTS\Smart-Sprayer\source\rpi\SmartSprayerV2\*" pi@PI_IP:/home/pi/SmartSprayerV2/
```

Or using `rsync` (preferred — only copies changed files):

```powershell
rsync -avz --exclude='__pycache__' --exclude='*.pyc' \
  "C:/Users/sajed/Desktop/PROJECTS/Smart-Sprayer/source/rpi/SmartSprayerV2/" \
  pi@PI_IP:/home/pi/SmartSprayerV2/
```

---

## Step 8 — Enable networkd-wait-online (WiFi Dependency)

The service waits for `network-online.target`. For this to work properly with WiFi, enable the network wait service:

```bash
sudo systemctl enable systemd-networkd-wait-online.service
```

Or, if your Pi uses `dhcpcd` (most common on Raspberry Pi OS):

```bash
sudo systemctl enable NetworkManager-wait-online.service
```

> To check which networking daemon is active: `systemctl is-active dhcpcd NetworkManager systemd-networkd 2>/dev/null`

---

## Step 9 — Enable and Start the Service

```bash
# Reload systemd to pick up the new file
sudo systemctl daemon-reload

# Enable the service (auto-start on every boot)
sudo systemctl enable smart-sprayer.service

# Start the service right now (without rebooting)
sudo systemctl start smart-sprayer.service
```

Check status immediately after starting:

```bash
sudo systemctl status smart-sprayer.service
```

You should see `Active: active (running)` and the GUI should appear on the touchscreen.

---

## Step 10 — Reboot and Verify

```bash
sudo reboot
```

Watch the touchscreen. Expected sequence:

1. Raspberry Pi bootloader (rainbow screen)
2. Raspberry Pi OS boot text
3. Desktop loads briefly
4. **Fullscreen splash screen** — "AUTOMATED SPRAYER SYSTEM" with loading bar
5. **Welcome screen** — "Mabuhay!" 
6. **Login screen** — sign in with `sprayer` / `1234`
7. **Main dashboard** — fullscreen control panel

---

## Step 11 — Touchscreen Calibration (if needed)

If touch input is inaccurate or inverted, calibrate the screen:

```bash
# Install calibration tool
sudo apt install xinput-calibrator -y

# Run the calibrator (run on the Pi desktop)
xinput_calibrator
```

Follow the on-screen prompts (tap the 4 crosshairs). Add the output to:

```bash
sudo nano /etc/X11/xorg.conf.d/99-calibration.conf
```

For screen rotation (e.g., portrait mode), add to `/boot/config.txt`:

```ini
# Rotate 90°
display_rotate=1

# Rotate 180°
display_rotate=2

# Rotate 270°
display_rotate=3
```

---

## Troubleshooting

### App does not appear on screen

```bash
# Check service logs
journalctl -u smart-sprayer.service -n 50 --no-pager

# Check if the service is active
systemctl status smart-sprayer.service
```

Common causes:
- **DISPLAY not set**: Make sure `Environment=DISPLAY=:0` is in the service file.
- **XAUTHORITY wrong**: Run `echo $XAUTHORITY` on the Pi desktop terminal to get the correct path.
- **Started too early**: Increase `ExecStartPre=/bin/sleep 5` to `10` or `15` seconds.

---

### App starts but crashes immediately

```bash
journalctl -u smart-sprayer.service -xe
```

Common causes:
- Missing Python packages → re-run `pip3 install -r requirements.txt`
- Firebase credentials missing or invalid → check `firebase_credentials.py`
- Wrong `WorkingDirectory` → relative imports fail if the working directory is wrong

---

### WiFi not connected when the app starts

The app needs WiFi for Firebase and weather APIs. If it starts before WiFi is up:

```bash
# Check which state network-online.target reaches
systemctl status network-online.target

# Increase the sleep delay in the service
sudo nano /etc/systemd/system/smart-sprayer.service
# Change:  ExecStartPre=/bin/sleep 5
# To:      ExecStartPre=/bin/sleep 15
```

Alternatively, add a WiFi wait loop to the ExecStartPre:

```ini
ExecStartPre=/bin/bash -c 'until ping -c1 8.8.8.8 &>/dev/null; do sleep 2; done'
```

---

### Touch does not work / wrong rotation

See **Step 11** above. Also check:

```bash
# List input devices
xinput list

# Test touch events
evtest /dev/input/event0   # replace event0 with your touchscreen device
```

---

### Disable or stop the service

```bash
# Stop immediately
sudo systemctl stop smart-sprayer.service

# Disable from autostart
sudo systemctl disable smart-sprayer.service
```

---

### View live logs while the app is running

```bash
journalctl -u smart-sprayer.service -f
```

---

## Quick Reference

| Task | Command |
|---|---|
| Start service | `sudo systemctl start smart-sprayer.service` |
| Stop service | `sudo systemctl stop smart-sprayer.service` |
| Restart service | `sudo systemctl restart smart-sprayer.service` |
| View status | `sudo systemctl status smart-sprayer.service` |
| View logs | `journalctl -u smart-sprayer.service -n 100` |
| Follow logs live | `journalctl -u smart-sprayer.service -f` |
| Enable on boot | `sudo systemctl enable smart-sprayer.service` |
| Disable on boot | `sudo systemctl disable smart-sprayer.service` |
| Reload after editing file | `sudo systemctl daemon-reload` |

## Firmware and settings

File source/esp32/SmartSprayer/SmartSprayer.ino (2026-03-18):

#include "PINS_CONFIG.h"
#include "GSM_CONFIG.h"
#include "RELAY_CONFIG.h"
#include "BUZZER_CONFIG.h"
#include "RTC_CONFIG.h"
#include "SR04_CONFIG.h"

// ============================================
// FRAMED PROTOCOL FUNCTIONS
// ============================================

// Calculate XOR checksum for framed protocol
uint8_t calculateChecksum(const String& data) {
  uint8_t checksum = 0;
  for (unsigned int i = 0; i < data.length(); i++) {
    checksum ^= data[i];
  }
  return checksum;
}

// Send framed response with checksum
void sendFramedResponse(const String& command, const String& data) {
  String payload = command + ":" + data;
  uint8_t checksum = calculateChecksum(payload);
  
  Serial.print("<");
  Serial.print(payload);
  Serial.print(":");
  Serial.print(checksum, HEX);
  Serial.println(">");
}

// Check if command is a framed command (starts with <)
bool isFramedCommand(const String& cmd) {
  return cmd.startsWith("<") && cmd.endsWith(">");
}

// Parse framed command and validate checksum
bool parseFramedCommand(const String& frame, String& command, String& data) {
  // Remove < and >
  String content = frame.substring(1, frame.length() - 1);
  
  // Find last colon (before checksum)
  int lastColon = content.lastIndexOf(':');
  if (lastColon < 0) return false;
  
  // Extract checksum
  String checksumStr = content.substring(lastColon + 1);
  String payload = content.substring(0, lastColon);
  
  // Validate checksum
  uint8_t receivedChecksum = strtol(checksumStr.c_str(), NULL, 16);
  uint8_t calculatedChecksum = calculateChecksum(payload);
  
  if (receivedChecksum != calculatedChecksum) {
    Serial.println("[ERROR] Checksum mismatch");
    return false;
  }
  
  // Parse command and data
  int firstColon = payload.indexOf(':');
  if (firstColon < 0) {
    command = payload;
    data = "";
  } else {
    command = payload.substring(0, firstColon);
    data = payload.substring(firstColon + 1);
  }
  
  return true;
}

// ============================================
// NON-BLOCKING SPRAY STATE MACHINE GLOBALS
// ============================================

// Spray state — updated atomically from loop(), never from an ISR.
struct SprayState {
  bool          active     = false;
  int           relay      = 0;
  int           volume     = 0;
  String        spray_type = "";
  unsigned long end_ms     = 0;
};
static SprayState spray_state;

// ============================================
// FIXED-SIZE SERIAL LINE BUFFER
// ============================================
// Replaces Serial.readStringUntil('\n') to avoid:
//   - Partial reads when bytes arrive across loop() iterations
//   - Heap fragmentation from dynamic String growth
//   - UART RX buffer overflow when ESP32 is "busy"
#define CMD_BUF_SIZE 256
static char cmd_buf[CMD_BUF_SIZE];
static int  cmd_len  = 0;
static bool cmd_ready = false;

void setup() {
  Serial.begin(9600);
  delay(1000);
  
  Serial.println("\n========================================");
  Serial.println("    SMART SPRAYER ESP32 - STARTING");
  Serial.println("========================================");
  
  Serial.print("[INIT] GSM Module... ");
  initGSM();
  Serial.println("READY");
  
  Serial.print("[INIT] Relays... ");
  initRELAY();
  Serial.println("READY");
  
  Serial.print("[INIT] Ultrasonic Sensors... ");
  initSR04();
  Serial.println("READY");
  
  Serial.print("[INIT] Buzzer... ");
  initBuzzer();
  Serial.println("READY");
  
  Serial.print("[INIT] RTC... ");
  initRTC();
  Serial.println("READY");
  
  Serial.println("========================================");
  Serial.println(" ALL SYSTEMS INITIALIZED - WAITING CMD");
  Serial.println("========================================\n");
}

void loop() {
  // Handle alarms (non-blocking 10 ms yield for TimeAlarms library)
  Alarm.delay(10);

  // ── NON-BLOCKING SPRAY TIMER ─────────────────────────────────────────────
  // Check if an active spray has reached its end time.
  // Uses signed cast to handle millis() rollover correctly.
  if (spray_state.active && (long)(millis() - spray_state.end_ms) >= 0) {
    // Turn relay OFF immediately.
    if (spray_state.relay == 1) {
      operateRELAY(RELAY_1, false);
    } else {
      operateRELAY(RELAY_2, false);
    }
    Serial.print("[SPRAY] Relay ");
    Serial.print(spray_state.relay);
    Serial.println(" OFF");

    // Send completion ACK to RPI BEFORE slow SMS so RPI can proceed.
    Serial.println("ACK:SPRAY_DONE");

    buzzerBeep(200);
    spray_state.active = false;
  }

  // ── GSM NETWORK RECONNECT CHECK ──────────────────────────────────────────
  // Rate-limited to once every 15 seconds. Skipped while an SMS is in progress.
  if (!smsInProgress && (long)(millis() - lastReconnectAttempt) >= 15000L) {
    lastReconnectAttempt = millis();
    checkNetwork();
    if (gsmNetworkState == NETWORK_DISCONNECTED ||
        gsmNetworkState == NETWORK_SEARCHING    ||
        gsmNetworkState == NETWORK_DENIED) {
      attemptReconnect();
    } else {
      readSignalStrength();
    }
  }

  // ── SIM800L unsolicited responses ────────────────────────────────────────
  if (sim.available() > 0) {
    String simResponse = sim.readStringUntil('\n');
    simResponse.trim();
    if (simResponse.length() > 0) {
      Serial.print("[SIM800L] ");
      Serial.println(simResponse);
      // Delivery status report from network
      if (simResponse.startsWith("+CDS:")) {
        handleDeliveryReport(simResponse);
      }
    }
  }

  // ── FIXED-SIZE SERIAL LINE BUFFER ────────────────────────────────────────
  // Read one byte at a time; assemble a complete line before processing.
  // This avoids partial reads and heap churn from readStringUntil().
  while (Serial.available() > 0) {
    char c = (char)Serial.read();
    if (c == '\n' || c == '\r') {
      if (cmd_len > 0) {
        cmd_buf[cmd_len] = '\0';
        cmd_ready = true;
        break;   // process one command per loop() iteration
      }
    } else if (cmd_len < CMD_BUF_SIZE - 1) {
      cmd_buf[cmd_len++] = c;
    }
    // Silently discard overflow bytes (command too long = malformed).
  }

  if (!cmd_ready) return;
  cmd_ready = false;

  // Build String from the static buffer for compatibility with existing
  // startsWith / indexOf processing below.
  String command = String(cmd_buf);
  cmd_len = 0;  // reset buffer for next command
  command.trim();    // remove any stray whitespace/CR
    
    // Check if this is a framed command
    if (isFramedCommand(command)) {
      String cmd, data;
      if (parseFramedCommand(command, cmd, data)) {
        // Handle framed commands
        if (cmd == "GET_LEVELS") {
          // Get both tank levels with moving average filtering
          long dist1 = readDistanceReliable(1, 3);
          long dist2 = readDistanceReliable(2, 3);
          
          float pct1 = (dist1 > 0) ? calculateFillPercentage(dist1, 1) : -1.0;
          float pct2 = (dist2 > 0) ? calculateFillPercentage(dist2, 2) : -1.0;
          
          // Build response data: dist1,pct1,dist2,pct2
          String responseData = String(dist1) + "," + String(pct1, 2) + "," + 
                               String(dist2) + "," + String(pct2, 2);
          
          sendFramedResponse("LEVELS", responseData);
        } else {
          Serial.print("[ERROR] Unknown framed command: ");
          Serial.println(cmd);
        }
      }
      return; // Don't process as regular command
    }
    
    // Regular (non-framed) command processing for backward compatibility
    Serial.print("[CMD] Received: ");
    Serial.println(command);
    
    if (command == "operate-relay1_on") {
      Serial.print("[RELAY] Turning Relay 1 ON... ");
      operateRELAY(RELAY_1, true);
      Serial.println("OK");
    } else if (command == "operate-relay1_off") {
      Serial.print("[RELAY] Turning Relay 1 OFF... ");
      operateRELAY(RELAY_1, false);
      Serial.println("OK");
    } else if (command == "operate-relay2_on") {
      Serial.print("[RELAY] Turning Relay 2 ON... ");
      operateRELAY(RELAY_2, true);
      Serial.println("OK");
    } else if (command == "operate-relay2_off") {
      Serial.print("[RELAY] Turning Relay 2 OFF... ");
      operateRELAY(RELAY_2, false);
      Serial.println("OK");
    } else if (command == "send-sms") {
      Serial.println("[GSM] Sending test SMS...");
      sendSMS("+1234567890", "Test SMS from Smart Sprayer");
      Serial.println("[GSM] Test SMS sent");
    } else if (command == "send-sms-to-all") {
      Serial.println("[GSM] Sending SMS to all recipients...");
      sendSMSToAll("Test SMS to all from Smart Sprayer");
      Serial.println("[GSM] Broadcast complete");
    } else if (command.startsWith("send-sms-to-all_")) {
      String customMsg = command.substring(16);
      Serial.println("[GSM] Sending custom SMS to all recipients...");
      sendSMSToAll(customMsg);
      Serial.println("[GSM] Broadcast complete");
    } else if (command == "test-gsm") {
      testGSMConnection();
    } else if (command == "check-network") {
      Serial.println("[GSM] Checking network status...");
      checkNetwork();
    } else if (command == "get-gsm-status") {
      readSignalStrength();
      printGSMStatus();
    } else if (command == "get-distance1") {
      Serial.print("[SR04] Reading Sensor 1... ");
      long dist = readDistanceReliable(1, 3);  // Use reliable reading with 3 attempts
      if (dist > 0) {
        Serial.print(dist);
        Serial.println(" cm");
      } else {
        Serial.println("Invalid reading (filtered out)");
      }
    } else if (command == "get-distance2") {
      Serial.print("[SR04] Reading Sensor 2... ");
      long dist = readDistanceReliable(2, 3);  // Use reliable reading with 3 attempts
      if (dist > 0) {
        Serial.print(dist);
        Serial.println(" cm");
      } else {
        Serial.println("Invalid reading (filtered out)");
      }
    } else if (command == "buzzer-on") {
      Serial.print("[BUZZER] Turning ON... ");
      buzzerOn();
      Serial.println("OK");
    } else if (command == "buzzer-off") {
      Serial.print("[BUZZER] Turning OFF... ");
      buzzerOff();
      Serial.println("OK");
    } else if (command == "buzzer-beep") {
      Serial.print("[BUZZER] Beeping... ");
      buzzerBeep();
      Serial.println("OK");
    } else if (command == "get-time") {
      Serial.print("[RTC] Reading time... ");
      String timeStr = getFormattedDateTime();
      Serial.println(timeStr);
    } else if (command.startsWith("set-rtc_")) {
      // Format: set-rtc_YY_MM_DD_HH_MM_SS
      // Example: set-rtc_26_02_01_14_30_00 (2026-02-01 14:30:00)
      String params = command.substring(8);
      int values[6];
      int idx = 0;
      int lastPos = 0;
      
      for (int i = 0; i < params.length() && idx < 6; i++) {
        if (params[i] == '_' || i == params.length() - 1) {
          int endPos = (i == params.length() - 1) ? i + 1 : i;
          values[idx++] = params.substring(lastPos, endPos).toInt();
          lastPos = i + 1;
        }
      }
      
      if (idx == 6) {
        setRTCTimeManual(values[0], values[1], values[2], values[3], values[4], values[5]);
      } else {
        Serial.println("[ERROR] Invalid format. Use: set-rtc_YY_MM_DD_HH_MM_SS");
      }
    } else if (command.startsWith("rtc-test_")) {
      // Test command to try different year values
      // Format: rtc-test_26
      int testYear = command.substring(9).toInt();
      Serial.print("[RTC] Testing year value: ");
      Serial.println(testYear);
      myRTC.setDS1302Time(0, 0, 0, 1, 1, 1, testYear);
      delay(200);
      myRTC.updateTime();
      Serial.print("[RTC] Result - year from RTC: ");
      Serial.println(myRTC.year);
    } else if (command.startsWith("sync-time_")) {
      // Format: sync-time_YY_MM_DD_HH_MM_SS
      // RPI syncs its time to ESP32 RTC
      String timeStr = command.substring(10);
      int values[6];
      int idx = 0;
      int lastPos = 0;
      for (int i = 0; i < timeStr.length() && idx < 6; i++) {
        if (timeStr.charAt(i) == '_') {
          values[idx++] = timeStr.substring(lastPos, i).toInt();
          lastPos = i + 1;
        }
      }
      if (idx == 5) {
        values[idx++] = timeStr.substring(lastPos).toInt();
      }
      
      if (idx == 6) {
        setRTCTimeManual(values[0], values[1], values[2], values[3], values[4], values[5]);
        Serial.println("[SYNC] Time synced from RPI");
      } else {
        Serial.println("[ERROR] Invalid time sync format");
      }
    } else if (command == "get-status") {
      // Return complete system status for RPI
      myRTC.updateTime();
      int year = myRTC.year;
      if (year > 2096) year = (year - 2096) + 2000;
      
      long dist1 = readDistanceReliable(1, 3);
      long dist2 = readDistanceReliable(2, 3);
      float pct1 = (dist1 > 0) ? calculateFillPercentage(dist1, 1) : -1.0;
      float pct2 = (dist2 > 0) ? calculateFillPercentage(dist2, 2) : -1.0;
      
      Serial.print("[STATUS] Time=");
      Serial.print(year);
      Serial.print("/");
      if (myRTC.month < 10) Serial.print("0");
      Serial.print(myRTC.month);
      Serial.print("/");
      if (myRTC.dayofmonth < 10) Serial.print("0");
      Serial.print(myRTC.dayofmonth);
      Serial.print(" ");
      if (myRTC.hours < 10) Serial.print("0");
      Serial.print(myRTC.hours);
      Serial.print(":");
      if (myRTC.minutes < 10) Serial.print("0");
      Serial.print(myRTC.minutes);
      Serial.print(":");
      if (myRTC.seconds < 10) Serial.print("0");
      Serial.print(myRTC.seconds);
      Serial.print(" Tank1=");
      if (pct1 >= 0) {
        Serial.print(pct1);
        Serial.print("%");
      } else {
        Serial.print("INVALID");
      }
      Serial.print(" Tank2=");
      if (pct2 >= 0) {
        Serial.print(pct2);
        Serial.print("%");
      } else {
        Serial.print("INVALID");
      }
      Serial.print(" Recipients=");
      Serial.println(numRecipients);
    } else if (command.startsWith("sync-recipients_")) {
      // Format: sync-recipients_NUM1,NUM2,NUM3
      // Clear existing and add all from RPI
      clearRecipients();
      String numbers = command.substring(16);
      
      if (numbers.length() > 0) {
        int lastPos = 0;
        for (int i = 0; i <= numbers.length(); i++) {
          if (i == numbers.length() || numbers.charAt(i) == ',') {
            String num = numbers.substring(lastPos, i);
            if (num.length() > 0) {
              addRecipient(num);
            }
            lastPos = i + 1;
          }
        }
      }
      Serial.print("[SYNC] Recipients synced: ");
      Serial.println(numRecipients);
    } else if (command == "get-level") {
      Serial.print("[SR04] Reading tank level... ");
      long dist = readDistanceReliable(1, 3);  // Use reliable reading with 3 attempts
      if (dist > 0) {
        float level = calculateFillLevel(dist);
        float percentage = calculateFillPercentage(dist, 1);  // sensorNum=1 so SMS alert fires
        if (percentage >= 0) {  // Valid percentage (not -1 for invalid readings)
          Serial.print("Dist=");
          Serial.print(dist);
          Serial.print("cm Fill=");
          Serial.print(level);
          Serial.print("cm (");
          Serial.print(percentage);
          Serial.println("%)");
        } else {
          Serial.println("Invalid reading (filtered out)");
        }
      } else {
        Serial.println("Invalid reading (filtered out)");
      }
    } else if (command == "get-levels") {
      // Get both tank levels for RPI
      Serial.print("[LEVELS] ");
      long dist1 = readDistanceReliable(1, 3);
      long dist2 = readDistanceReliable(2, 3);
      
      // Debug prints
      Serial.print("[DEBUG] Dist1=");
      Serial.print(dist1);
      Serial.print("cm Dist2=");
      Serial.print(dist2);
      Serial.print("cm ");
      
      float pct1 = (dist1 > 0) ? calculateFillPercentage(dist1, 1) : -1.0;
      float pct2 = (dist2 > 0) ? calculateFillPercentage(dist2, 2) : -1.0;
      
      // Debug prints
      Serial.print("Pct1=");
      Serial.print(pct1);
      Serial.print(" Pct2=");
      Serial.print(pct2);
      Serial.print(" ");
      
      // Only show valid readings
      if (pct1 >= 0) {
        Serial.print("Tank1=");
        Serial.print(pct1);
        Serial.print("% ");
      } else {
        Serial.print("Tank1=INVALID ");
      }
      
      if (pct2 >= 0) {
        Serial.print("Tank2=");
        Serial.print(pct2);
        Serial.println("%");
      } else {
        Serial.println("Tank2=INVALID");
      }
    } else if (command.startsWith("spray_")) {
      // Format: spray_RELAY_DURATION_VOLUME_SPRAYTYPE
      // Example: spray_1_60_5000_Pesticide  (Relay 1, 60 s, 5000 mL, Pesticide)
      // SPRAYTYPE is optional (defaults to "Unknown" for backward compatibility)
      //
      // NON-BLOCKING IMPLEMENTATION:
      //   1. Relay turns ON IMMEDIATELY after argument parsing.
      //   2. ACK:SPRAY_STARTED is sent to the RPI so it knows the relay is
      //      physically active.
      //   3. A millis() timer is set; the loop() state machine turns the relay
      //      OFF when the timer expires (spray timer check at top of loop).
      //   4. SMS and buzzer notifications fire AFTER relay OFF so they can
      //      never delay actual relay actuation.

      if (spray_state.active) {
        Serial.println("[SPRAY] Busy - another spray is in progress");
      } else {
        int idx1 = command.indexOf('_');
        int idx2 = command.indexOf('_', idx1 + 1);
        int idx3 = command.indexOf('_', idx2 + 1);
        int idx4 = command.indexOf('_', idx3 + 1);  // Optional spray type index

        if (idx3 > 0) {
          int    relay     = command.substring(idx1 + 1, idx2).toInt();
          int    duration  = command.substring(idx2 + 1, idx3).toInt();
          int    volume;
          String sprayType;

          if (idx4 > 0) {
            // New format: spray_RELAY_DURATION_VOLUME_SPRAYTYPE
            volume    = command.substring(idx3 + 1, idx4).toInt();
            sprayType = command.substring(idx4 + 1);
          } else {
            // Legacy format: spray_RELAY_DURATION_VOLUME
            volume    = command.substring(idx3 + 1).toInt();
            sprayType = "Unknown";
          }

          Serial.print("[SPRAY] Starting: Relay ");
          Serial.print(relay);
          Serial.print(", Duration ");
          Serial.print(duration);
          Serial.print("s, Volume ");
          Serial.print(volume);
          Serial.println("mL");

          // ── RELAY ON IMMEDIATELY ─────────────────────────────────────────
          // Relay activates before any SMS/buzzer blocking call.
          if (relay == 1) {
            operateRELAY(RELAY_1, true);
          } else {
            operateRELAY(RELAY_2, true);
          }
          Serial.print("[SPRAY] Relay ");
          Serial.print(relay);
          Serial.println(" ON");

          // Acknowledge to RPI: relay is physically ON right now.
          Serial.println("ACK:SPRAY_STARTED");

          // Arm the non-blocking timer.
          spray_state.active     = true;
          spray_state.relay      = relay;
          spray_state.volume     = volume;
          spray_state.spray_type = sprayType;
          spray_state.end_ms     = millis() + (unsigned long)duration * 1000UL;

          // Buzzer: short beep is acceptable (relay is already ON).
          buzzerBeep(200);
          // NOTE: Spray-started SMS is now sent from the Raspberry Pi
          // via Semaphore API (see hardware/esp32_hardware.py :: spray()).
        } else {
          Serial.println("[ERROR] Invalid spray format. Use: spray_RELAY_DURATION_VOLUME");
        }
      }
    } else if (command.startsWith("add-recipient_")) {
      String number = command.substring(14);
      Serial.print("[GSM] Adding recipient... ");
      addRecipient(number);
    } else if (command.startsWith("remove-recipient_")) {
      String number = command.substring(17);
      Serial.print("[GSM] Removing recipient... ");
      removeRecipient(number);
    } else if (command == "clear-recipients") {
      Serial.print("[GSM] Clearing all recipients... ");
      clearRecipients();
    } else if (command == "list-recipients") {
      Serial.println("[GSM] Listing recipients:");
      listRecipients();
    } else if (command.startsWith("send-sms-custom_")) {
      int firstUnderscore = command.indexOf('_');
      int secondUnderscore = command.indexOf('_', firstUnderscore + 1);
      if (secondUnderscore > 0) {
        String number = command.substring(firstUnderscore + 1, secondUnderscore);
        String message = command.substring(secondUnderscore + 1);
        Serial.print("[GSM] Sending custom SMS to ");
        Serial.print(number);
        Serial.print("... ");
        sendSMS(number, message);
        Serial.println("OK");
      } else {
        Serial.println("[ERROR] Invalid SMS format");
      }
    } else {
      Serial.print("[ERROR] Unknown command: ");
      Serial.println(command);
    }
}

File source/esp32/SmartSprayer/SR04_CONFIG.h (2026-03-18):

#ifndef SR04_CONFIG_H
#define SR04_CONFIG_H

// Arduino.h and PINS_CONFIG.h are included first in SmartSprayer.ino

const int trigPin = TRIG_PIN;
const int echoPin = ECHO_PIN;
const int trig2Pin = TRIG2_PIN;
const int echo2Pin = ECHO2_PIN;

// Moving average filter configuration
#define MOVING_AVG_WINDOW 5

// Moving average buffers for smooth readings
long sensor1Buffer[MOVING_AVG_WINDOW] = {0};
long sensor2Buffer[MOVING_AVG_WINDOW] = {0};
int sensor1Index = 0;
int sensor2Index = 0;
bool sensor1BufferFilled = false;
bool sensor2BufferFilled = false;

// Function prototypes
long calculateMovingAverage(int sensorNum);

void initSR04() {
  pinMode(trigPin, OUTPUT);
  pinMode(echoPin, INPUT);
  pinMode(trig2Pin, OUTPUT);
  pinMode(echo2Pin, INPUT);
  
  // Initialize buffers with invalid readings
  for (int i = 0; i < MOVING_AVG_WINDOW; i++) {
    sensor1Buffer[i] = 0;
    sensor2Buffer[i] = 0;
  }
}

long readDistance() {
  digitalWrite(trigPin, LOW);
  delayMicroseconds(2);
  digitalWrite(trigPin, HIGH);
  delayMicroseconds(10);
  digitalWrite(trigPin, LOW);
  long duration = pulseIn(echoPin, HIGH);
  long distance = duration * 0.034 / 2;
  return distance;
}

long readDistance2() {
  digitalWrite(trig2Pin, LOW);
  delayMicroseconds(2);
  digitalWrite(trig2Pin, HIGH);
  delayMicroseconds(10);
  digitalWrite(trig2Pin, LOW);
  long duration = pulseIn(echo2Pin, HIGH);
  long distance = duration * 0.034 / 2;
  return distance;
}

// Reliable distance reading with filtering
long readDistanceReliable(int sensorNum = 1, int maxAttempts = 3) {
  long readings[5]; // Fixed size array for simplicity
  int validCount = 0;
  
  // Take multiple readings
  for (int i = 0; i < maxAttempts && validCount < 5; i++) {
    long distance = (sensorNum == 1) ? readDistance() : readDistance2();
    
    // Only consider valid readings (not 0 and within reasonable range)
    if (distance > 0 && distance <= CONTAINER_EMPTY_DISTANCE + 20) {
      readings[validCount] = distance;
      validCount++;
    }
    
    delay(50); // Small delay between readings
  }
  
  // If we have valid readings, return the median
  if (validCount > 0) {
    // Sort readings (simple bubble sort for small array)
    for (int i = 0; i < validCount - 1; i++) {
      for (int j = 0; j < validCount - 1 - i; j++) {
        if (readings[j] > readings[j + 1]) {
          long temp = readings[j];
          readings[j] = readings[j + 1];
          readings[j + 1] = temp;
        }
      }
    }
    
    // Get median value
    long median = readings[validCount / 2];
    
    // Add to moving average buffer
    if (sensorNum == 1) {
      sensor1Buffer[sensor1Index] = median;
      sensor1Index = (sensor1Index + 1) % MOVING_AVG_WINDOW;
      if (sensor1Index == 0) sensor1BufferFilled = true;
    } else {
      sensor2Buffer[sensor2Index] = median;
      sensor2Index = (sensor2Index + 1) % MOVING_AVG_WINDOW;
      if (sensor2Index == 0) sensor2BufferFilled = true;
    }
    
    // Calculate moving average
    return calculateMovingAverage(sensorNum);
  }
  
  // If all readings were invalid, return 0 (will be filtered out)
  return 0;
}

// Calculate moving average from buffer
long calculateMovingAverage(int sensorNum) {
  long* buffer = (sensorNum == 1) ? sensor1Buffer : sensor2Buffer;
  bool bufferFilled = (sensorNum == 1) ? sensor1BufferFilled : sensor2BufferFilled;
  
  long sum = 0;
  int count = bufferFilled ? MOVING_AVG_WINDOW : 
              ((sensorNum == 1) ? sensor1Index : sensor2Index);
  
  // If no readings yet, return 0
  if (count == 0) return 0;
  
  // Sum valid readings in buffer
  int validCount = 0;
  for (int i = 0; i < count; i++) {
    if (buffer[i] > 0) {  // Skip invalid readings (0)
      sum += buffer[i];
      validCount++;
    }
  }
  
  // Return average of valid readings
  return (validCount > 0) ? (sum / validCount) : 0;
}

// Container level calculation functions
// Sensor: Standard HC-SR04 (non-waterproof), min range ~2 cm
// Container specs:
//   Full  (100% / 16 L) : sensor reads ~12–15 cm → nominal CONTAINER_FULL_DISTANCE  = 13 cm
//   Empty (0%)          : sensor reads ~41 cm    → CONTAINER_EMPTY_DISTANCE = 41 cm
//   Usable range        : 41 − 13 = 28 cm
// Distance → percentage mapping:
//   ≤ 13 cm   → 100%   (liquid at or above the full mark)
//   13–41 cm  → proportional over the 28 cm usable range
//   ≥ 41 cm   → 0%    (tank empty)
// SMS alert thresholds (fired once per drop; re-armed when level recovers):
//   Critical : liquid height ≤ 5.0 cm  (= 20% of 25 cm usable range)
//   Empty    : distance ≥ 41 cm  (liquid height = 0 cm)

// Critical liquid-height threshold in cm (20% × 25 cm usable range = 5.0 cm)
#define CRITICAL_LIQUID_HEIGHT_CM 5.0f

// Per-sensor SMS debounce flags  [index 0 unused; 1 = Tank 1, 2 = Tank 2]
static bool s_critical_sent[3] = {false, false, false};
static bool s_empty_sent[3]    = {false, false, false};
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

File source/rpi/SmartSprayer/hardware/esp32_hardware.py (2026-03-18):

# esp32_hardware.py
# Hardware implementation that communicates with ESP32 via USB serial
# ESP32 handles all physical hardware components
#
# Serial transport is managed by hardware.esp32_connection.ESP32Connection
# which handles auto-detection, auto-reconnect, and port persistence.

import serial
import time
import threading
import sys
import os
import requests
from hardware.hardware_interface import HardwareInterface
from hardware.esp32_connection import (
    ESP32Connection,
    STATE_CONNECTED,
    _list_serial_ports,
)

# Import container configuration
sys.path.insert(0, os.path.dirname(os.path.dirname(os.path.abspath(__file__))))
from PINS_CONFIG import CONTAINER_EMPTY_DISTANCE, CONTAINER_FULL_DISTANCE, CONTAINER_CAPACITY_LITERS

# ============================================
# SEMAPHORE API – RPI-side SMS (replaces ESP32 SIM800L)
# ============================================

def _normalize_phone(number: str) -> str:
    """Convert +63XXXXXXXXX to 09XXXXXXXXX for the Semaphore API."""
    number = number.strip()
    if number.startswith('+63'):
        return '0' + number[3:]
    if number.startswith('63') and len(number) >= 12:
        return '0' + number[2:]
    return number  # Already in local format or unknown — pass through


def send_sms_via_semaphore(numbers: list, message: str) -> bool:
    """Send SMS to a list of phone numbers via Semaphore API (bulk, one request).

    Args:
        numbers:  List of phone number strings (+63 or 09 format).
        message:  SMS body text.

    Returns:
        True on HTTP 2xx response, False otherwise.
    """
    from core.app_settings import get_semaphore_api_key
    api_key = get_semaphore_api_key()
    if not api_key:
        print("[SMS] Semaphore API key not configured — SMS not sent.")
        return False

    normalized = [_normalize_phone(n) for n in numbers if n]
    if not normalized:
        print("[SMS] No valid recipients — SMS not sent.")
        return False

    url = "https://api.semaphore.co/api/v4/messages"
    payload = {
        "apikey": api_key,
        "number": ",".join(normalized),
        "message": message,
    }
    try:
        response = requests.post(url, data=payload, timeout=15)
        print(f"[SMS] Semaphore response: {response.status_code}")
        return response.ok
    except Exception as e:
        print(f"[SMS] Semaphore API error: {e}")
        return False

# ============================================
# FRAMED PROTOCOL FUNCTIONS
# ============================================

def calculate_checksum(data: str) -> int:
    """Calculate XOR checksum for framed protocol"""
    checksum = 0
    for char in data:
        checksum ^= ord(char)
    return checksum

def validate_frame(frame: str) -> tuple:
    """
    Validate and parse framed response
    Returns: (valid, command, data_dict)
    """
    if not frame or not frame.startswith('<') or not frame.endswith('>'):
        return (False, None, None)
    
    # Remove < and >
    content = frame[1:-1]
    
    # Split by colons
    parts = content.split(':')
    if len(parts) != 3:
        return (False, None, None)
    
    command, data, checksum_str = parts
    
    # Validate checksum
    try:
        received_checksum = int(checksum_str, 16)
        payload = f"{command}:{data}"
        calculated_checksum = calculate_checksum(payload)
        
        if received_checksum != calculated_checksum:
            print(f"[FRAME ERROR] Checksum mismatch: expected {calculated_checksum:X}, got {received_checksum:X}")
            return (False, None, None)
    except ValueError:
        print(f"[FRAME ERROR] Invalid checksum format: {checksum_str}")
        return (False, None, None)
    
    # Parse data based on command
    if command == "LEVELS":
        # Format: dist1,pct1,dist2,pct2
        data_parts = data.split(',')
        if len(data_parts) == 4:
            try:
                data_dict = {
                    'dist1': int(data_parts[0]),
                    'pct1': float(data_parts[1]),
                    'dist2': int(data_parts[2]),
                    'pct2': float(data_parts[3])
                }
                return (True, command, data_dict)
            except ValueError as e:
                print(f"[FRAME ERROR] Failed to parse LEVELS data: {e}")
                return (False, None, None)
    
    return (False, None, None)
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

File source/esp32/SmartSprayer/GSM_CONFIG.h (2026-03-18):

#ifndef GSM_CONFIG_H
#define GSM_CONFIG_H

// #include <SoftwareSerial.h>  // Commented out for HardwareSerial
// PINS_CONFIG.h is included first in SmartSprayer.ino

#define MAX_RECIPIENTS 10

HardwareSerial sim(1); // UART1 for ESP32

// ── GSM Network State ─────────────────────────────────────────────────────
enum GSMNetworkState {
  NETWORK_DISCONNECTED,   // Not registered, not searching
  NETWORK_SEARCHING,      // Searching for a network
  NETWORK_CONNECTED,      // Registered (home or roaming)
  NETWORK_DENIED,         // Registration denied
  NETWORK_RECONNECTING    // Actively attempting reconnection
};

GSMNetworkState gsmNetworkState   = NETWORK_DISCONNECTED;
bool            smsInProgress     = false;   // Reconnect guard: skip while sending SMS
unsigned long   lastReconnectAttempt = 0;   // millis() timestamp of last reconnect cycle
int             csqValue          = 99;      // Last RSSI reading (99 = unknown)
String          cregResponse      = "";     // Last raw +CREG stat field (e.g. "0,1")

// Dynamic recipients array (managed by RPI via serial commands)
String recipients[MAX_RECIPIENTS];
int numRecipients = 0;

// ── GSM Helper / Monitoring Functions ──────────────────────────────────────

String getSignalLevelString(int rssi) {
  if (rssi == 99) return "UNKNOWN";
  if (rssi <= 9)  return "POOR";
  if (rssi <= 14) return "WEAK";
  if (rssi <= 19) return "GOOD";
  return "EXCELLENT";
}
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

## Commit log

2025-12-20 Update LCD and RELAY config headers with implementation
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2025-12-20 Update NTP_CONFIG.h with full header-only NTP implementation for ESP32
2025-12-20 Add centralized PIN configuration module
    - Created PINS_CONFIG.h with all hardware pin definitions
    - Updated SR04_CONFIG.h, RELAY_CONFIG.h, GSM_CONFIG.h, LCD_CONFIG.h to use centralized pins
    - Updated README.md with new pin configuration section and project structure
    [Smart-Sprayer.fzz]
2025-12-20 Add support for second ultrasonic sensor
    - Updated PINS_CONFIG.h with pins for second sensor (GPIO 14 Trig, GPIO 16 Echo)
    - Modified SR04_CONFIG.h to include readDistance2() function
    - Updated SmartSprayer.ino serial commands for both sensors
    - Updated README.md documentation for dual sensor setup
2025-12-20 Add buzzer and LED indicator modules
    - Created BUZZER_CONFIG.h with buzzer control functions
    - Created LED_CONFIG.h with system status LED functions (OK and Error)
    - Updated PINS_CONFIG.h with buzzer and LED pin definitions
    - Modified SmartSprayer.ino to include and initialize new modules
    - Added serial commands for buzzer and LED testing
    - Updated README.md with new hardware, pins, commands, and API reference
    [PINS_CONFIG.h, SmartSprayer.ino]
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2025-12-20 Add comprehensive serial testing commands for LCD, NTP, WiFi, and button functions
2025-12-20 Add missing functionality: container level calculation, SSR control, manual LED control, and additional NTP commands
    [PINS_CONFIG.h, SR04_CONFIG.h, SmartSprayer.ino]
2025-12-20 Add comprehensive button system with LCD menu navigation and DS1302 RTC for spray scheduling
2025-12-20 Switch to DS3231 RTC with updated pin configurations and GSM PWR_KEY
    [Smart-Sprayer.fzz]
2025-12-20 Update wiring diagrams for Smart-Sprayer
    [Smart-Sprayer.fzz]
2025-12-20 Update PINS_CONFIG and wiring diagrams
    [Smart-Sprayer.fzz]
2025-12-21 Update wiring diagrams
    [Smart-Sprayer.fzz]
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2025-12-21 Restructure flowchart as one cohesive diagram: remove all subgraphs for continuous flow
2025-12-21 Redesign flowchart as step-by-step process starting from ESP32 button scheduling
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2025-12-21 Update README.md to reflect current project state
    - Restructured usage section to focus on button-based scheduling
    - Updated serial interface as diagnostics tool rather than testing interface
    - Added v1.2.0 to version history documenting flowchart redesign
    - Emphasized step-by-step operational flow from button scheduling
    - Removed testing commands from operational documentation
2025-12-21 Remove Version History and Future Enhancements sections from README.md
    - Removed Version History section (v1.2.0, v1.1.0, v1.0.0 entries)
    - Removed Future Enhancements section (GPS, ML models, mobile app, etc.)
    - Streamlined README.md to focus on current project state
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2026-01-14 Update wiring files
    [Smart-Sprayer.fzz]
2026-01-20 Add complete Smart Sprayer GUI with CustomTkinter
    - Beautiful farmer-friendly UI with 5 main panels (Dashboard, Scheduling, Previous Data, Notifications, Logs)
    - Advanced scheduling with auto-adjust logic for conflict resolution and interval preservation
    - Hardware abstraction layer supporting both PC mock mode and Raspberry Pi real hardware
    - Comprehensive logging system and data persistence
    - Real-time tank monitoring for 2 containers
    - Complete documentation and testing tools
    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
2026-01-31 Remove button, LCD, and LED functionality from ESP32 code; add model images
2026-01-31 Refactor RPI to communicate with ESP32 via serial
    - Remove direct GPIO hardware control from RPI
    - Delete hardware-specific CONFIG files (button, LCD, LED, buzzer, relay, sensors, etc.)
    - Create ESP32Hardware class for serial communication with ESP32
    - Update hardware_interface to support ESP32 mode or PC mock mode
    - Simplify SmartSprayer.py to CLI stub (GUI is primary interface)
    - Update requirements.txt to include pyserial
    - Add comprehensive RPI_ESP32_ARCHITECTURE.md documentation
    - Preserve all GUI functionality - dashboard, scheduling, logs, etc.
    - RPI now serves as GUI/controller, ESP32 handles all physical hardware
    [PINS_CONFIG.py, esp32_hardware.py, hardware_interface.py]
2026-01-31 Remove mock hardware - RPI only uses ESP32 serial communication
    - Delete mock_hardware.py (no longer needed for PC testing)
    - Remove PC_MODE flag from hardware_interface.py
    - Simplify get_hardware() to only return ESP32Hardware
    - Add configurable serial port parameters (port, baudrate, timeout)
    - Update documentation to reflect ESP32-only architecture
    - RPI now exclusively communicates with ESP32 via serial
    [hardware_interface.py]
2026-01-31 Rename logs to spraying events logs
    - Rename logs_viewer.py to spraying_events_logs_viewer.py
    - Update class name from LogsViewerPanel to SprayingEventsLogsViewerPanel
    - Change UI tab from 'System Logs' to 'Spraying Events Logs'
    - Update all method names: refresh_logs -> refresh_spraying_events_logs
    - Update button text: 'Clear Logs' -> 'Clear Spraying Events Logs'
    - Update status messages and error messages to reference spraying events logs
    - Update import statements in main_ui.py
2026-01-31 Clean RPI codebase for ESP32 USB serial communication
    - Remove unused config files (FIREBASE, WEATHER, WIFI)
    - Remove .idea IDE folder (added to .gitignore)
    - Update .gitignore with Python, IDE, and OS-specific entries
    - Remove unused imports from SmartSprayer.py
    - Add USB serial port documentation to esp32_hardware.py
    - Update architecture documentation with cleanup details
    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
2026-01-31 Add volume-based spray scheduling with automatic duration calculation
    - Add volume input field (mL) in scheduling UI with default 1000 mL
    - Calculate spray duration based on pump rate (5L/min = 5000 mL/min)
    - Update scheduler to use volume_ml instead of duration parameter
    - Display volume and calculated duration in dashboard, schedules, and history
    - Store volume_ml in schedule and history data
    - Add VOLUME_BASED_SCHEDULING.md documentation with examples
2026-01-31 Remove WiFi/Firebase from ESP32, add Firebase integration to RPI with Pyrebase4
    ESP32 Changes:
    - Remove WiFi_CONFIG.h, FIREBASE_CONFIG.h, NTP_CONFIG.h, WEATHER_CONFIG.h
    - Remove WiFi, Firebase, NTP, and Weather API dependencies
    - Simplify to hardware-only operations (GSM, Relay, Sensors, Buzzer, RTC)
    - Remove WiFi-dependent commands (wifi-reset, check-weather, ntp commands)
    - Add set-time command for RPI to sync ESP32 time if needed
    RPI Changes:
    - Add Pyrebase4 to requirements.txt for Firebase integration
    - Create firebase_service.py for cloud data sync
    - Create weather_service.py for weather API integration (via RPI)
    - Update data_store.py to auto-sync with Firebase
    - Create firebase_crede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
    [SmartSprayer.ino]
2026-01-31 Add automatic weather-based scheduling with rain detection
    - Integrate weather service into scheduler for automatic weather checks
    - Check current weather and 24h forecast before executing sprays
    - Auto-reschedule sprays when rain detected or forecasted
    - Postpone by 1 day with max 3 reschedules (configurable)
    - Cancel schedule after max reschedules to prevent infinite postponement
    - Add check_weather_for_schedule() for manual weather verification
    - Add check_forecast_for_rain() for 24h rain prediction
    - Configure Manila weather credentials in template
    - Store weather reason in reschedule metadata
    - Log all weather-based decisions
    - Create comprehensive WEATHER_INTEGRATION.md documentation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
2026-01-31 Complete GSM recipient management migration and RTC fixes
    - Migrated GSM recipients from ESP32 hardcoded files to RPI GUI settings
    - Removed FIREBASE_CREDENTIALS.h, GSM_RECIPIENTS.h, GSM_RECIPIENTS_template.h, WEATHER_CREDENTIALS.h from ESP32
    - Added dynamic recipient management via serial commands (add-recipient, remove-recipient, list-recipients)
    - Created RPI settings panel for recipient management with Firebase sync
    - Updated ESP32 to use DS1302 RTC with proper pin configuration (CLK=18, DAT=5, RST=19)
    - Added comprehensive debug prints with [CATEGORY] prefixes
    - Added GSM communication test command (test-gsm)
    - Fixed RTC initialization and time formatting to match working sample
    - Added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
    [GSM_CONFIG.h, PINS_CONFIG.h, RELAY_CONFIG.h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]
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2026-02-04 Update wiring diagram files
    [Smart-Sprayer.fzz]
2026-02-04 Fix date picker calendar not working on RPi by replacing tkcalendar with comboboxes
    [run_gui.py]
2026-02-04 Convert Smart Sprayer UI to light theme
    - Changed all dark backgrounds (#1E1E1E, #2B2B2B, #121212) to light colors
    - Updated sidebar to light green (#E8F5E9) and content area to light gray (#F5F5F5)
    - Changed text colors from white/gray to dark colors for better readability
    - Preserved green (#4CAF50) and red (#F44336) button colors for actions
    - Updated all frames, cards, and containers to light theme
    - Maintained semantic color coding for status indicators and progress bars
2026-02-04 Fix ESP32 communication parsing errors and scheduling panel initialization
    - Fix ESP32 tank level parsing to handle 'Tank1=X%' format correctly
    - Add command echo filtering to prevent parsing command responses as data
    - Improve error handling in distance and level reading functions
    - Add safety checks in SchedulingPanel to prevent AttributeError on date_entry
    - Enhance error messages for better debugging
    [esp32_hardware.py]
2026-02-04 Fix scheduling panel initialization and ESP32 command echo parsing
    - Update scheduling panel safety check for new date widget structure (year/month/day combo boxes)
    - Improve ESP32 response parsing to filter out '[CMD] Received:' acknowledgments
    - Prevent parsing of command echoes as data responses
    - Fix 'Scheduling panel not properly initialized' error
    [esp32_hardware.py]
2026-02-04 Fix _clear_form method to work with new date widget structure
    - Remove references to non-existent date_entry widget in _clear_form method
    - Update form clearing to reset year/month/day combo boxes to current date
    - Fix 'NoneType object has no attribute configure' error after schedule creation
2026-02-04 Fix threading issues in UI panels - prevent 'main thread is not in main loop' errors
    - Use tkinter's after() method to schedule UI updates on main thread
    - Fix spraying_events_logs_viewer auto-refresh to be thread-safe
    - Fix dashboard update loop to schedule updates properly
    - Fix notifications panel update loop to avoid direct widget access from background threads
    - Add error handling for destroyed widgets
    - Prevents RuntimeError when background threads try to update UI
2026-02-07 Fix Weather API credentials import issue
    - Add explicit path handling in weather_service.py and firebase_service.py
    - Prevent false 'Weather API credentials not found' warnings
    - Enhance error handling and validation for credential imports
    - Add detailed status logging for weather service initialization
    - Ensure imports work regardless of current working directory
2026-02-07 Add hourly weather forecast display to dashboard
    - Implement hourly caching system in weather_service.py
    - Add weather information panel to dashboard UI
    - Display current temperature, humidity, wind, rain, and UV index
    - Cache weather data to update only once per hour (7am, 8am, 9am, etc.)
    - Reduce API calls by 99.94% while maintaining fresh data
    - Add color-coded indicators for rain and UV levels
    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
2026-02-07 Fix Firebase connection for pyrebase4 compatibility
    - Add pyrebase4/pyrebase import fallback mechanism
    - Fix 'Firebase service not available' error on RPI
    - Enhance Firebase initialization with detailed logging
    - Add device status updates to Firebase RTDB
    - Create comprehensive Firebase connection test script
    - Add complete documentation for Firebase setup and troubleshooting
    - Maintain backward compatibility with existing credentials
    - Follow working RoboSort Firebase pattern for reliability
2026-02-07 Fix ultrasonic container level configuration: 22cm=full(16L), 70cm=empty(0L)
    [PINS_CONFIG.h, PINS_CONFIG.py, SR04_CONFIG.h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]
2026-02-08 Implement ultrasonic sensor filtering with 3 readings and proper percentage mapping
    ESP32 Firmware:
    - Add readDistanceReliable() function: takes 3 readings, filters out 0cm invalid readings
    - Use median of valid readings for stability
    - Update calculateFillPercentage() for proper mapping:
    * 0-22cm = 100% (FULL)
    * 22-80cm = interpolated percentage
    * 80cm+ = 0% (EMPTY)
    - Update all sensor commands (get-distance, get-level, get-levels, get-status) to use reliable reading
    - Add invalid reading detection and handling
    Raspberry Pi:
    - Update CONTAINER_EMPTY_DISTANCE from 70cm to 80cm
    - Add filtering for invalid readings (-1.0 from ESP32)
    - Improve percentage calculation with boundary checks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
    [PINS_CONFIG.py, SR04_CONFIG.h, SmartSprayer.ino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]
2026-02-08 Fix RPI handling of INVALID ultrasonic sensor readings from ESP32
    - Add check for 'INVALID' string before float conversion in get_tank_level_percentage()
    - Add check for 'INVALID' string before float conversion in get_both_tank_levels()
    - Return 0.0 (0%) for INVALID readings instead of crashing
    - Add try-catch blocks for safer float conversion
    Fixes error: 'could not convert string to float: INVALID'
    [esp32_hardware.py]
2026-02-08 Keep previous tank level values when ultrasonic readings are invalid
    Hardware Layer (esp32_hardware.py):
    - Return None instead of 0.0 for INVALID ultrasonic readings in get_tank_level_percentage()
    - Don't include tank keys in dict when readings are INVALID in get_both_tank_levels()
    - This allows UI to detect invalid readings and keep displaying previous values
    Dashboard (dashboard.py):
    - Add last_tank1_level and last_tank2_level instance variables to track last known good values
    - Only update tracked levels when valid readings are received (not None, key exists in dict)
    - Always display last known good values, preventing jumps to 0% on invalid readings
    Notifications (notifications.py):
    - A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
    [esp32_hardware.py]
2026-02-08 Change tank level mapping from 22-80cm to 22-50cm range
    - PINS_CONFIG.h: CONTAINER_EMPTY_DISTANCE = 50.0 (was 80.0)
    - SR04_CONFIG.h: Updated comments and calculations for 22-50cm range
    - Usable range now 28cm (50-22) instead of 58cm (80-22)
    - PINS_CONFIG.py: CONTAINER_EMPTY_DISTANCE = 50.0 (was 80.0)
    - CONTAINER_HEIGHT updated to 28cm
    - esp32_hardware.py: Updated comments and interpolation calculations
    Tank Level Mapping:
    - 22cm = 100% FULL (16L)
    - 50cm = 0% EMPTY (0L)
    - More sensitive readings in shorter range for better accuracy
    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
    [PINS_CONFIG.h, PINS_CONFIG.py, SR04_CONFIG.h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]
2026-02-08 Add debug prints to show ESP32 responses for ultrasonic distance commands
    - Added debug prints in _send_command() for distance-related commands
    - Added detailed parsing debug in get_tank_level_percentage()
    - Added detailed parsing debug in get_both_tank_levels()
    - Added parsing debug in get_status() method
    - Shows raw ESP32 responses and RPI parsing steps for troubleshooting
2026-02-08 Add debug prints to ESP32 get-levels command to troubleshoot tank2 readings
    - Added debug output showing raw distance readings for both sensors
    - Added debug output showing calculated percentages before formatting
    - Shows Dist1, Dist2, Pct1, Pct2 values to identify where tank2 reading fails
    - Helps diagnose if issue is with sensor hardware, filtering, or calculation
    [SmartSprayer.ino]
2026-02-08 Fix tank2 dashboard updates by improving ESP32 serial reads and get-levels parsing
    [esp32_hardware.py]
2026-02-08 Redesign ESP32-RPI serial protocol with framed messages, checksums, and moving average filter
    - Implement framed protocol with <COMMAND:data:checksum> format
    - Add XOR checksum validation for error detection
    - Implement 5-reading moving average filter on ESP32
    - Update ultrasonic distance rules (0cm=INVALID, 1-22cm=100%, >50cm=0%)
    - Add GET_LEVELS framed command with automatic fallback
    - Maintain full backward compatibility with old commands
    - Add comprehensive documentation (SERIAL_PROTOCOL.md, PROTOCOL_UPGRADE_GUIDE.md)
    - Improve dashboard smoothness and eliminate flickering
    [SR04_CONFIG.h, SmartSprayer.ino, esp32_hardware.py]
2026-02-08 Fix ESP32 compilation error: add calculateMovingAverage function prototype
    [SR04_CONFIG.h]
2026-02-08 Remove RPI terminal output for ultrasonic sensor operations
    - Remove [ESP32 DEBUG] prints for get-distance, get-level, get-levels commands
    - Remove [RPI DEBUG] prints for tank level parsing operations
    - Remove [FRAME] prints for Tank1/Tank2 readings
    - Keep error messages ([FRAME ERROR], [FRAME TIMEOUT]) for debugging issues
    - Keep debug output for non-ultrasonic operations (relays, SMS, status)
    - Clean terminal output while maintaining error reporting
    [esp32_hardware.py]
2026-02-08 Fix UI lag caused by GET_LEVELS timeout
    - Reduce framed protocol timeout from 1s to 150ms to prevent UI freezing
    - Disable framed protocol permanently after first failure to avoid repeated timeouts
    - Remove spammy timeout messages for cleaner console output
    - ESP32 firmware doesn't support new framed protocol yet, so fallback to old protocol
    [esp32_hardware.py]
2026-02-08 Fix UI blocking issues in scheduler
    - Make weather API calls non-blocking with threading and timeouts
    - Remove blocking sleep during spray execution
    - Execute spray operations in background threads
    - Add ThreadPoolExecutor for parallel operations
    - Graceful error handling for weather check failures
2026-02-23 Updated GUI
    [Smart-Sprayer.fzz]
2026-02-23 Complete backend fixes: SMS, tank alerts, weather min/max, path corrections
    [esp32_hardware.py]
2026-02-23 Fix Tkinter modal grab_set error by ensuring window is visible before grabbing
    [run_gui.py]
2026-02-23 fix: resolve Python 3.13 threading error; add rain forecast to V2 dashboard
    - notifications.py: replace background thread that called self.after() with
    separate _fetch_hardware_loop (only blocking I/O, no tkinter) and
    _main_update_loop (self.after() periodic from main thread)
    - dashboard.py: same pattern - _fetch_data_loop does hardware+weather I/O,
    _update_loop is now main-thread self.after() based
    - weather_service.py: add get_forecast_data() and get_forecast_data_cached()
    - dashboard.py: add Rain Forecast UI section (Today/Tomorrow chance%, mm,
    alert banner) matching SmartSprayer V1 feature
2026-02-23 feat: skip mobile screen for returning users, send login SMS instead
    - After login, check session for saved phone number
    - First-time user (no phone saved): show MobileNumberScreen as before
    - Returning user (phone already registered): skip MobileNumberScreen,
    send login notification SMS to saved number, go directly to dashboard
    [run_gui.py]
2026-02-23 fix: resolve ESP32 'get-levels' port conflict in V2 dashboard
    - Root cause: _fetch_data_loop called get_tank1_level() and
    get_tank2_level() separately; each internally called get_both_tank_levels()
    which sent 'get-levels' twice in rapid succession on the same serial port,
    causing 'device reports readiness to read but returned no data' error.
    - Fix: call get_both_tank_levels() once per loop iteration and unpack
    both tank levels from the returned dict (single serial round-trip).
    - Also added get_both_tank_levels() to HardwareInterface base class.
    [hardware_interface.py]
2026-02-26 Implement singleton hardware, serial lock, ACK-based spray, non-blocking ESP32 state machine, and UI improvements
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2026-03-04 Fix ultrasonic level calculation, blind zone, and SMS alerts for critical/empty levels. Update container height to 38cm everywhere.
    [PINS_CONFIG.h, PINS_CONFIG.py, SR04_CONFIG.h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]
2026-03-05 Fix ambiguous overload: remove duplicate sendSMSToAll forward declaration in SR04_CONFIG.h
    [SR04_CONFIG.h]
2026-03-05 Integrate Firebase RTDB authentication for login, password change, and logout. Syncs account to RTDB, validates login against RTDB, and updates password in RTDB. Fixes logout flow to return to login 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
    [run_gui.py]
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2026-03-05 Fix SMS alert threshold: fire at 20% tank level (not 10%). Also fix get-level command to pass correct sensorNum for SMS trigger.
    [SmartSprayer.ino]
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2026-03-07 Remove auto-reconnect, manual connect only, fix USB dropdown population
    [esp32_connection.py, esp32_hardware.py]
2026-03-07 Fix: share single hardware instance across app; get_hardware() is now a singleton
    [hardware_interface.py]
2026-03-07 Feat: replace Onboard with in-app 1024x200 virtual keyboard (KeyboardManager)
    [run_gui.py]
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2026-03-07 Fix: add keyboard icon next to login entries for manual toggle
    [run_gui.py]
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2026-03-08 Fix SMS notification workflow: hardware reconnect, recipient sync, AT command handling, custom broadcast message, auto-resync on reconnect
    [GSM_CONFIG.h, SmartSprayer.ino, esp32_hardware.py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]
2026-03-17 feat(gsm): enable SMS delivery reports and print delivery status in serial monitor
2026-03-17 fix: enable SIM800L delivery reports in text mode, resolve merge conflict in GSM_CONFIG.h
    [GSM_CONFIG.h]
2026-03-18 Fix: resolve arduino-builder panic and SIM800L SMS ERROR (include guards, CSMP, sendSMS)
    [GSM_CONFIG.h, RELAY_CONFIG.h, SR04_CONFIG.h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]
2026-03-18 Refactor: Replace SIM800L SMS with Semaphore API, implement anti-spam, secure API key, and shorten SMS messages
    [SmartSprayer.ino, esp32_hardware.py]
